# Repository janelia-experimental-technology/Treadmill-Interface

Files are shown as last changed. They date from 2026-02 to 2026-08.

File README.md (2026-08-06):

# Treadmill-Interface
Interface to treadmill encoder with USB-serial and analog outputs

Provides an interface to a treadmill that uses an incremental encoder to monitor speed and distance.
The speed and distance are calculated at each increment of the encoder. Time, speed, and distance are sent out a serial-USB port. The minimum time between readinsg can be set, as well as the time to wait to set zero speed.
The absolute value of speed is also sent out to an SMA connector as an analog signal. Direction is sent out another SMA connector as a 3.3V digital signal. 
The design utilizes a Teensy 4.0.
The encoder voltage provided is 5 volts.

PCB design done in Eagle
Firmware design in Arduino with Teensy extensions
Processor - Teensy 4.0

**Opportunity:** Free to make for Non-Profit Research by downloading the design here. See included hardware license.

Commercial licenses are also available, contact innovation@janelia.hhmi.org and reference this DOI.

For inquiries, please contact [innovation@janelia.hhmi.org](mailto:innovation@janelia.hhmi.org) and reference: Janelia 2017-055

To cite the designs, please cite this DOI: [https://doi.org/10.25378/janelia.33179270](https://doi.org/10.25378/janelia.33179270)

**Related to:** https://doi.org/10.25378/janelia.24691311, item 2017-049

**Other:** supersedes Flintbox ID: 2017-055

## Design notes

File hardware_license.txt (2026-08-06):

Copyright © 2025 Howard Hughes Medical Institute

By downloading, using and/or viewing these designs, documentation and related data and information, and all content in the foregoing (collectively, the “Designs”), you agree to the following:

You may use, copy, modify, display and distribute the Designs for any non-commercial research or educational purpose.

THE DESIGNS ARE PROTOTYPES AND ARE EXPERIMENTAL IN NATURE AND SHOULD BE USED WITH PRUDENCE AND APPROPRIATE CAUTION, AS NOT ALL OF THE CHARACTERISTICS ARE KNOWN. THE DESIGNS ARE PROVIDED “AS-IS” WITHOUT ANY EXPRESS OR IMPLIED WARRANTIES OF ANY KIND (INCLUDING, BUT NOT LIMITED TO, ANY IMPLIED WARRANTIES OF MERCHANTABILITY, NON-INFRINGEMENT, TITLE, ACCURACY, OR FITNESS FOR A PARTICULAR PURPOSE, AND ANY WARRANTIES ARISING FROM COURSE OF PERFORMANCE, COURSE OF DEALING, COURSE OF CONDUCT, OR USAGE OF TRADE) OR CONDITIONS OF ANY KIND, WHETHER EXPRESS OR IMPLIED OR STATUTORY. NO OPINION, ADVICE OR STATEMENT OF THE HOWARD HUGHES MEDICAL INSTITUTE (“HHMI”) OR ITS TRUSTEES, EMPLOYEES, AGENTS, LICENSORS OR SUPPLIERS, WHETHER MADE WITHIN THE DESIGNS OR OTHERWISE, SHALL CREATE ANY WARRANTY. HHMI MAKES NO WARRANTY THAT THE DESIGNS WILL BE ACCURATE, CURRENT OR RELIABLE. SOME JURISDICTIONS DO NOT ALLOW THE EXCLUSION OF CERTAIN WARRANTIES OR CONDITIONS, AND AS A CONSEQUENCE SOME OF THE ABOVE DISCLAIMERS MAY NOT APPLY TO YOU. 

IN NO EVENT SHALL HHMI OR ITS TRUSTEES, EMPLOYEES, AGENTS, LICENSORS OR SUPPLIERS (THE “HHMI PARTIES”) BE LIABLE FOR ANY DIRECT, INDIRECT, INCIDENTAL, SPECIAL, EXEMPLARY, CONSEQUENTIAL, OR PUNITIVE DAMAGES OR LOSSES OF ANY KIND (INCLUDING, BUT NOT LIMITED TO, ANY PROCUREMENT OF SUBSTITUTE GOODS OR SERVICES; LOSS OF USE, BUSINESS, GOODWILL, DATA, REVENUE, OR PROFITS; REASONABLE ROYALTIES; BUSINESS INTERRUPTION; OR OTHER INTANGIBLE LOSSES) HOWEVER CAUSED AND ON ANY THEORY OF LIABILITY, WHETHER IN CONTRACT, STRICT LIABILITY, TORT (INCLUDING, WITHOUT LIMITATION, NEGLIGENCE) OR OTHERWISE, ARISING IN ANY WAY OUT OF THE USE OF, OR INABILITY TO USE, THE DESIGNS, OR FOR ANY OTHER CLAIM RELATED IN ANY WAY TO YOUR USE OF THE DESIGNS OR YOUR INTERACTIONS WITH HHMI, EVEN IF ADVISED OF THE POSSIBILITY OF SUCH DAMAGE OR LOSS, AND NOTWITHSTANDING THE FAILURE OF ESSENTIAL PURPOSE OF ANY LIMITED REMEDY. YOU ACKNOWLEDGE THAT THESE LIMITATIONS ARE REASONABLE, THAT THEY ARE AN ESSENTIAL ELEMENT HEREOF, AND THAT ABSENT SUCH LIMITATIONS, HHMI WOULD NOT MAKE THE DESIGNS AVAILABLE TO YOU OR ENTER INTO THESE TERMS AND CONDITIONS. YOU REMAIN RESPONSIBLE FOR ALL LEGAL COMPLIANCE WITH RESPECT TO YOUR USAGE OF THE DESIGNS. SOME JURISDICTIONS DO NOT ALLOW THE LIMITATION OF LIABILITY FOR INCIDENTAL OR CONSEQUENTIAL DAMAGES, AND AS A CONSEQUENCE SOME OF THE ABOVE LIMITATIONS MAY NOT APPLY TO YOU; IN SUCH JURISDICTIONS, THE LIABILITY OF THE HHMI PARTIES SHALL BE LIMITED TO THE FULLEST EXTENT PERMITTED BY LAW.

Any redistribution of the Designs must contain or reference these terms.

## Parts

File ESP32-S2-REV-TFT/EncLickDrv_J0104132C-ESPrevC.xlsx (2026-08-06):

Partlist exported from Z:/ID&F/TreadmillWithLick/EncoderLickDriver/ECAD/EncLickDrv_J0104132C-ESPrevB.sch at 7/21/2025 11:48 AM
Qty | Value | Device | Designators | Manufacturer | Man PN | Vendor | Vendor PN | $ea | $Total | Notes
1 |  | CON5104361-4 | J7 | TE | 5-104361-4
3 |  | CON21881558 | J3 J4 J6 | Phoenix Contact | 1881558 |  |  | $1.05
1 |  | CON81844743 | J5 | Phoenix Contact | 1848668 |  |  | $7.75
2 |  | DIODE_SCHOTTKYPWRDI-123 | D1 D2 | Diodes Inc | DFLS240-7 | DK | DFLS240-7DIDKR-ND | $0.25
1 |  | POWER_JACK_SHUNTPJ-002 | J1 | CUI | PJ-002BH-SMT-TR |  |  | $1.31
1 | 0 ohm | RESISTOR_SM0805S | R1 | Bournes | CR0805-J/-000ELF | DK | CR0805-J/-000ELFCT-ND | $0.10
3 | 0.1 | CAPS0603S | C2 C4 C5 | Kemet | C0603C104K5RACTU |  |  | $0.11
1 | 0.1 NPO | CAPS1206S | C1 | Kemet | C1206C104J4GACAUTO |  |  | $1.54
1 | 2G17 | 2G17 | U4 | TI | SN74LVC2G17DBVR |  |  | $0.40
2 | 909 | RES SMD 909 OHM 1% 1/8W 0805 | R3 R4 | Stackpole Electronics Inc | RMCF0805FT909R | DK | RMCF0805FT909RCT-ND | $0.10
1 | 53048-05 | 53048-05 | J2 | Molex | 530480560 | DK | 900-0530480560-ND | $0.67
1 | ESP32=S2-REV-TFT-NO16-21 | ESP32=S2-REV-TFT-NO16-21 | M1 | Adafruit | 5345 |  |  | $24.95
2 | RELAY_SSR | RELAY_SSR | U2 U3 | IXYS | CPC1014N |  |  | $1.25
1 | TLV9301 | AD8065RT | U1 | Analog Devices | AD8603AUJZ-REEL |  |  | $2.62
2 | 10K0 ohm | RES SMD 10K OHM 1% 1/8W 0805 | R2 R5 | Bourns | CR0805-FX-1002ELF | DK | CR0805-FX-1002ELFCT-ND | $0.10
 |  | Mate for 1991558 |  | Phoenix | 1881325 |  |  | $2.80
1 | 5 pin header RA | CONN HEADER R/A 5POS 2.54MM | J2 | TE | 5-104361-4 | DK | A33964-ND | $1.74 | Alternate
 |  |  |  |  |  |  | TOTAL | $46.74
 |  | BOARD design can be found at:
 |  | https://oshpark.com/shared_projects/oZUU0shd

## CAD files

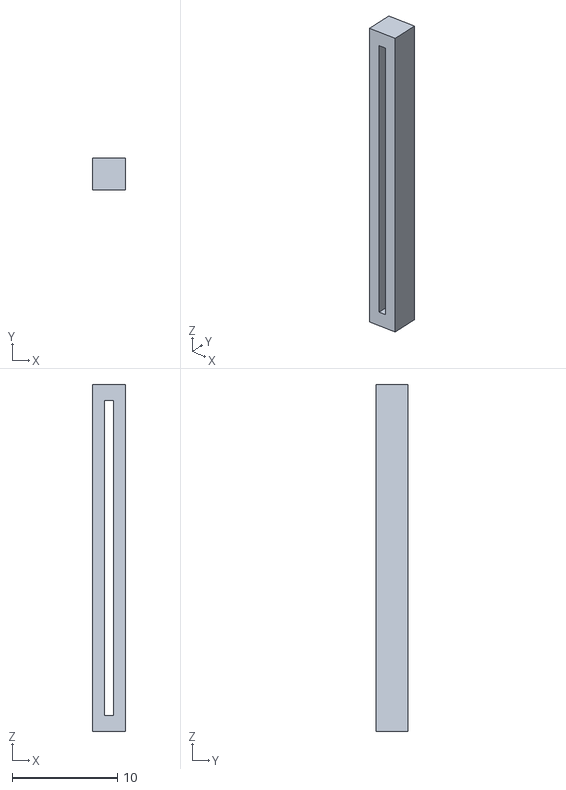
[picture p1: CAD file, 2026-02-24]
MCAD/riser12pin.stl
3.17 x 3.05 x 33.0

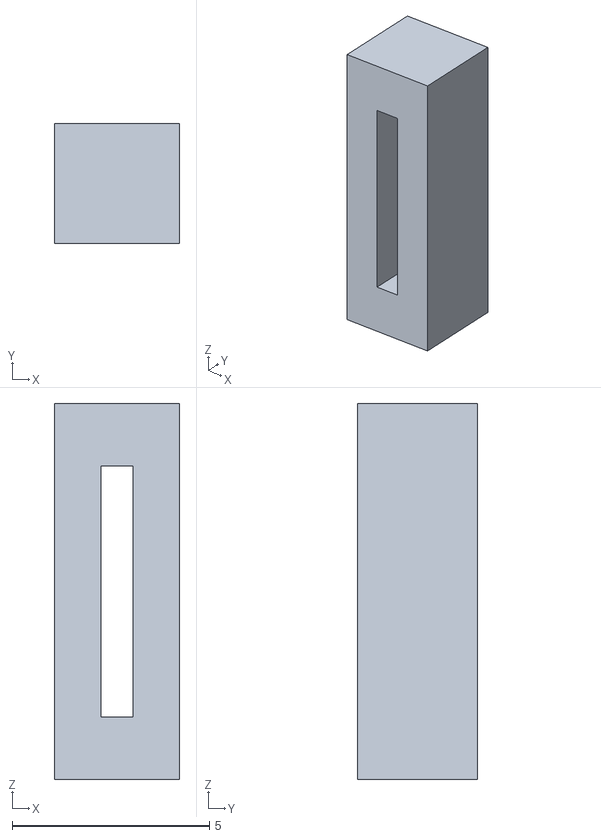
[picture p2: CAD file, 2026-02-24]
MCAD/riser3pin.stl
3.17 x 3.05 x 9.52

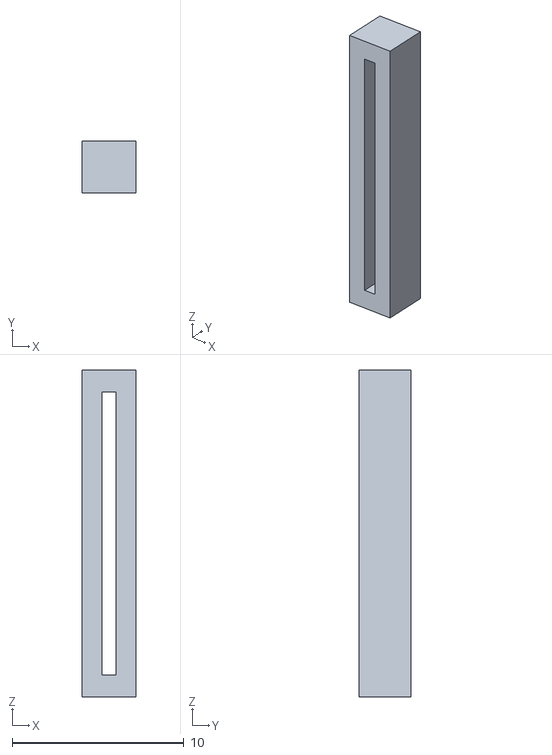
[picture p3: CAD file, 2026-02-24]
MCAD/riser7pin.stl
3.17 x 3.05 x 19.0

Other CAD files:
MCAD/BLK-esp32-rev-tft-back-largeEncoderConn.ipt
MCAD/BLK-esp32-rev-tft-bezel.ipt
MCAD/OldVersions/riser12pin.0003.ipt
MCAD/OldVersions/riser3pin.0002.ipt
MCAD/OldVersions/riser7pin.0001.ipt
MCAD/riser12pin.ipt
MCAD/riser3pin.ipt
MCAD/riser7pin.ipt

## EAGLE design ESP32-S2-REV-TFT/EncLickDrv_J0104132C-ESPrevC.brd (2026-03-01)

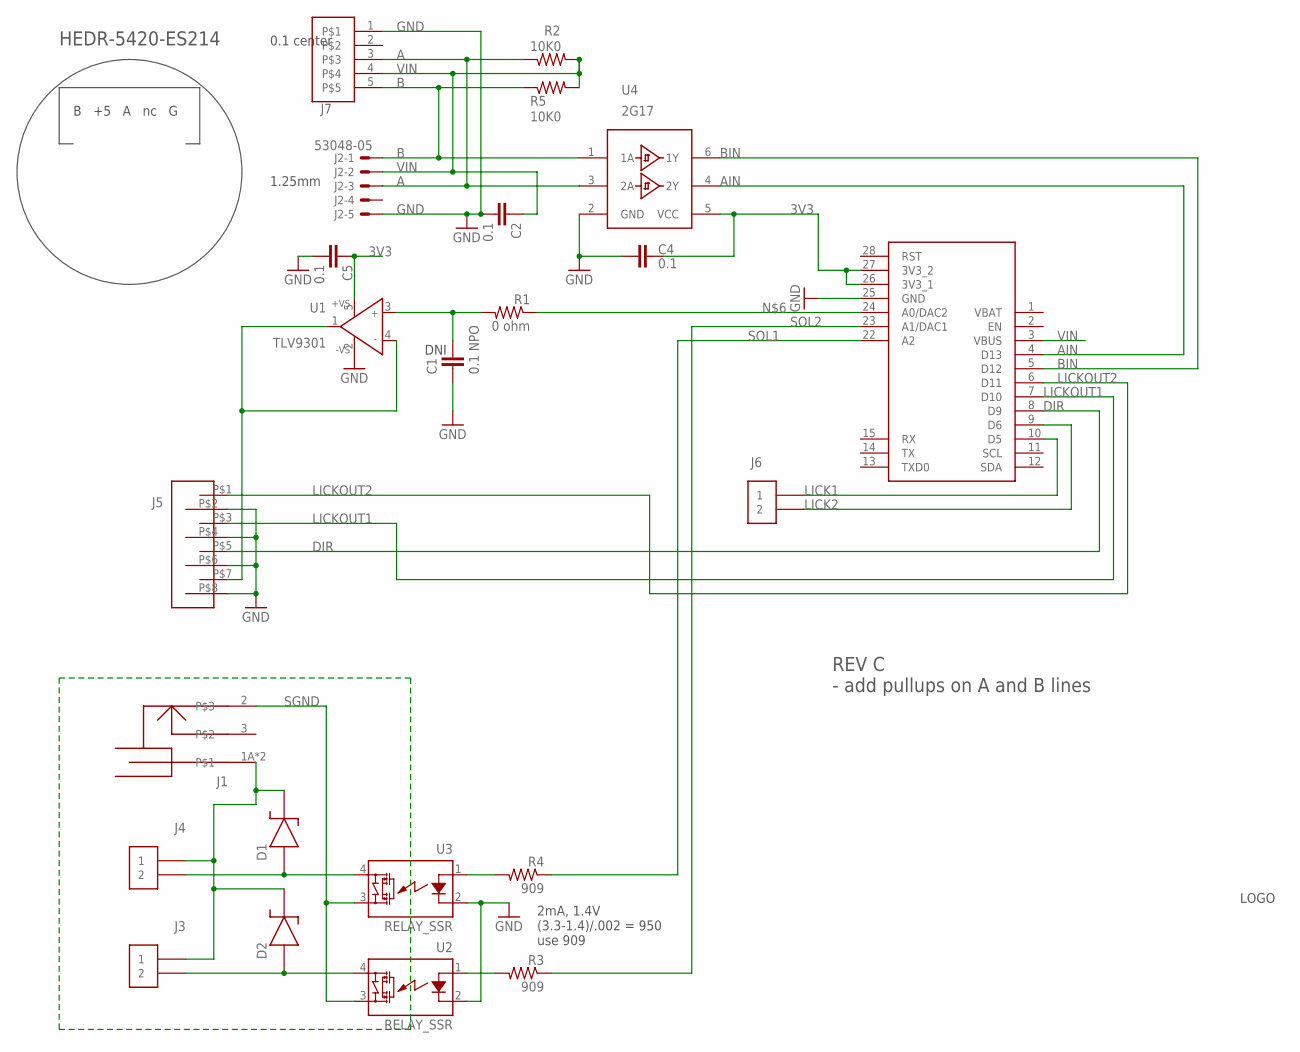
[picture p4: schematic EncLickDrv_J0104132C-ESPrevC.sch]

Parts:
C1: 0.1 NPO; 1206S
C2, C4, C5: 0.1; 0603S
D1, D2: DIODE_SCHOTTKYPWRDI-123; PWRDI-123
J1: POWER_JACK_SHUNTPJ-002; PJ-002
J2: 53048-05
J3, J4, J6: CON21881558; 1881558
J5: CON81844743; 1844743
J7: CON5104361-4; 104361-4
M1: ESP32=S2-REV-TFT-NO16-21; ESP32-S2-REV-TFT-NO16-21
R1: 0 ohm; 0805S
R2, R5: 10K0; 0805S
R3, R4: 909; 0805S
U1: TLV9301; SOT23-5
U2, U3: RELAY_SSR; SSR_SOIP
U4: 2G17; SOT23-6
U$1: JFRC-LOGOLOGO_OP; LOGO_BMP_OP

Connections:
3V3: C4.1, C5.1, M1.26 (3V3_1), M1.27 (3V3_2), U1.5 (+VS), U4.5 (VCC)
A: J2.3, J7.3, R2.1, U4.3 (2A)
AIN: M1.4 (D13), U4.4 (2Y)
B: J2.1, J7.5, R5.1, U4.1 (1A)
BIN: M1.5 (D12), U4.6 (1Y)
DIR: J5.P$5 (5), M1.8 (D9)
GND: C1.2, C2.2, C4.2, C5.2, J2.5, J5.P$2 (2), J5.P$4 (4), J5.P$6 (6), J5.P$8 (8), J7.1, M1.25 (GND), U1.2 (-VS), U2.2 (K), U3.2 (K), U4.2 (GND)
LICK1: J6.1, M1.10 (D5)
LICK2: J6.2, M1.9 (D6)
LICKOUT1: J5.P$3 (3), M1.7 (D10)
LICKOUT2: J5.P$1 (1), M1.6 (D11)
unnamed: D1.A, J4.2, U3.4 (DS1)
unnamed: D2.A, J3.2, U2.4 (DS1)
unnamed: D1.K, D2.K, J1.1A, J1.1B, J3.1, J4.1
unnamed: M1.24 (A0/DAC2), R1.1
unnamed: R4.2, U3.1 (A)
unnamed: R3.2, U2.1 (A)
unnamed: J5.P$7 (7), U1.1 (OUT), U1.4 (IN-)
unnamed: C1.1, R1.2, U1.3 (IN+)
SGND: J1.2, U2.3 (DS2), U3.3 (DS2)
SOL1: M1.22 (A2), R4.1
SOL2: M1.23 (A1/DAC1), R3.1
VIN: C2.1, J2.2, J7.4, M1.3 (VBUS), R2.2, R5.2

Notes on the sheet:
B +5 A nc G
HEDR-5420-ES214
1.25mm
2mA, 1.4V (3.3-1.4)/.002 = 950 use 909
DNI
0.1 center
REV C - add pullups on A and B lines

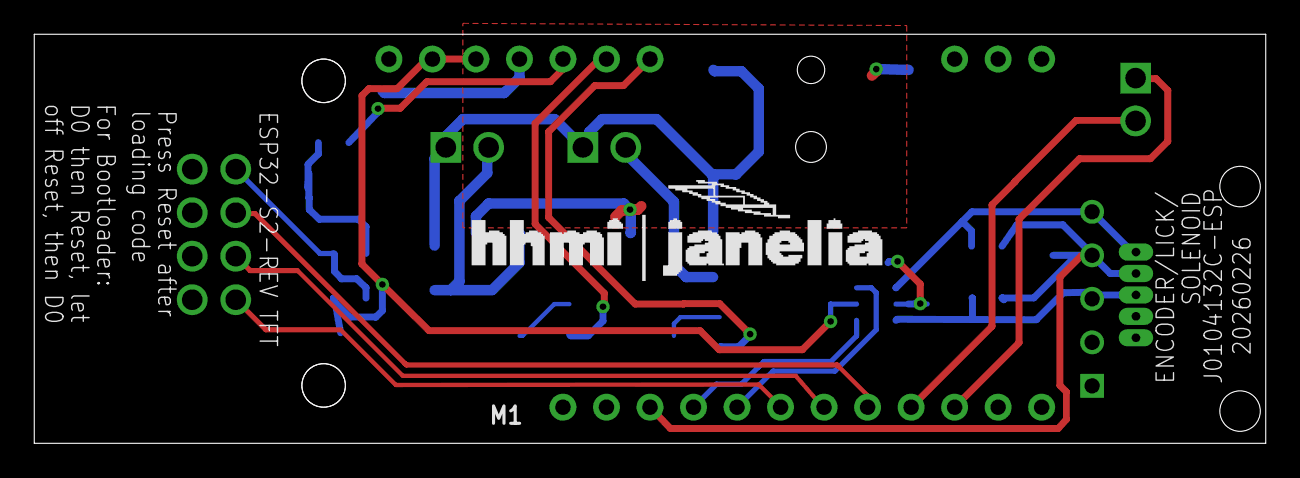
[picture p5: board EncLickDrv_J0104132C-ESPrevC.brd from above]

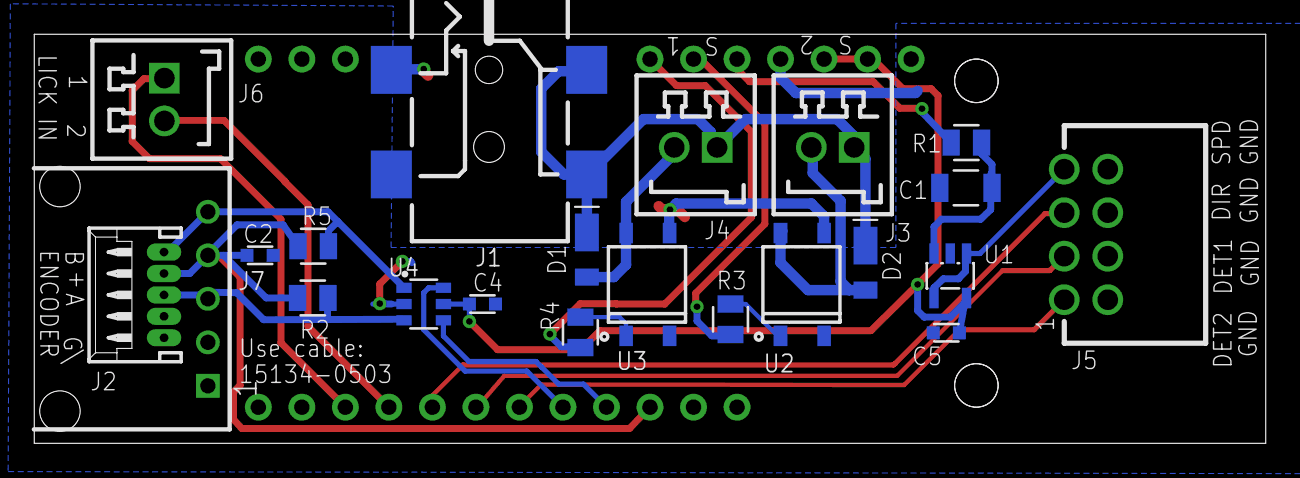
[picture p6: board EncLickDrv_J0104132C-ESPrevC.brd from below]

Board: 2 copper layers, 71.9 x 23.9 mm, 24 parts (23 on the bottom side), 23 nets.

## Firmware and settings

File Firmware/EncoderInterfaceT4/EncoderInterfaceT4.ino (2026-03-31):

 // EncoderInterfaceT4
//
//  Read the encoder and translate to a distance and send over USB-Serial and PWM DAC
//  Teensy 4.0 with Teensy Extensions

//  Encoder A - pin 14
//  Encoder B - pin 15
//  Encoder VCC - Vin
//  Encoder ground - GND
//  PWM Analog Out - pin 3
//  Direction pin - pin 21
//
// Steve Sawtelle
// jET
// Janelia
// HHMI 
//

#define SHOW_MICROS    // if defined, print micros() with each output
#define SHOW_REVERSE   // if this is defined, show abs value of speed, else ignore reverse distance/speed
#define SHOW_ZERO      // if this is defined, show 0 speed if no movement in SPEED_TIMEOUT micros
//#define CYLINDER_8IN   // if this is defined, will compile for 8" cyclinder, else standard belt 

#define ZERO_OFFSET    // if this is defined, offset zero to 1/2 Max DAC to allow sending reverse speed through DAC
//                          if used must also define SHOW_REVERSE

#define UPDATE_USECS 20000  // don't print faster than this many micros
#define SPEED_TIMEOUT 100000  // if we don't move in this many micros assume we are stopped and show 0.0 speed 


#define VERSION "20260331"
// ===== VERSIONS ======

// 20260331 sws
// - implemement zero offset 

// 20240909 sws
// - from EncoderInterfaceT3, changes to use Teensy 4.0
//   pin changes
//   add in spped and dir outputs, speed is PWM analog

// 20230621 sws
// - add ability to compile for cylinder treadmill

// 20230523 sws
// - remove debug output in loop
// - add '?' query for version

// 20220419 sws
// - update lastUsecs during zero speed time so that when the treadmill starts again the speed 
//   is based on the end of last zero time out

// 20221212 sws from suggestions by york at Labmaker
// - strict even intervals causes poor low speed granularity
// - so, return to incremental updates, but limit to no faster than UPDATE_USECS 
// - make define to allow showing zero if no movement in SPEED_TIMEOUT micros
// - add define to allow printing of micros() value

// 20221017 sws
// - add define to print distance and speed at even intervals. 
//     To use allow #define TIMED_UPDATE and UPDATE_RATE sets the rate in updates per second

// 20220720 sws
// - also need to use pin 3 not 0 in LC as 0 doesn't have interrupt capability
// - to keep backward compatibility, set the unused pin as input so they can be tied
//    together on PCB

// 20220711 sws
// - provide alternate compile for Teensy LC, A12 not A14 for DAC

// 20211109 sws
// - was printing absolute run speed, now it shows as negative if reverse

// 20211021 sws
// - add define for offsetting DAC to show reverse speed 

// 20180514 sws
// - DIR pin was set to 12 but hardware has it on 2
// - also had index pin as 2 should be 14

// 20180328 sws
// - remove wait for serial since it will not move past it if no serial port is defined

// 20180319 sws
// - add define to allow showing reverse direction

#define MAXSPEED    1000.0f  // maximum speed for dac out (mm/sec)
#define MAXDACVOLTS 2.5f    // DAC ouput voltage at maximum speed
#define MAXDACCNTS  4095.0f // maximum dac value - should be 2^(analogWriteResolution)

float maxDACval = MAXDACVOLTS * MAXDACCNTS / 3.3; // limit dac output to max allowed

#define speedPin 3    
#define encAPin 14 // 12
#define encBPin 15 // 11
#define dirPin 21    // 0 = forward,1 = reverse


#ifdef CYLINDER_8IN
// counts per rotation of cylindrical treadmill encoder wheel: 200 counts per rev, 7.90" per rev (was 7.95)
// so - 7.90 * 25.4 * pi / 200  = microns/cnt
// when using rising and falling edges of both channels, must divide by 800
// first version of cylinder used /200 and then /4 in distance per count, but the /4 should be here
#define MM_PER_COUNT 787990  // 3171909  // actually 1/10^6mm per count since we divide by usecs
#else
// counts per rotation of treadmill encoder wheel
// 200 counts per rev
// 1.03" per rev
// so - 1.03 * 25.4 * pi / 200 /1000 = microns/cnt
#define MM_PER_COUNT 410950  // actually 1/10^6mm per count since we divide by usecs
#endif

#define DIST_PER_COUNT ((float)MM_PER_COUNT/1000000.0)   //(float)0.41095
 
#define SPEED_TIMEOUT 100000  // if we don't move in this many microseconds assume we are stopped

static float runSpeed = 0;
static float lastSpeed = 0;
volatile uint32_t lastUsecs;
volatile uint32_t thisUsecs;
volatile uint32_t encoderUsecs;
volatile float distance = 0;
volatile float deltaDistance = 0;
volatile int8_t encoderCounts = 0;

#define FW 1
#define BW -1

int dir = FW;

float lastDistance;
float zeroDistance;
volatile boolean movement = false;

// ------------------------------------------
// interrupt routine for ENCODER_A rising edge (and falling if cylinder)
// ---------------------------------------------
void encoderInt()
{   
   thisUsecs = micros();
  
  int ENCA = digitalReadFast(encAPin);  // always update output 
  int ENCB = digitalReadFast(encBPin); 
  // figure out the direction  
    
  if (ENCA == ENCB )  // if same, then backwards
  {   
    dir = BW;
    #ifdef SHOW_REVERSE 
        distance -= DIST_PER_COUNT;
    #endif
  }  
  else
  {
      dir = FW;
      distance += DIST_PER_COUNT;
  }  
   
  #ifndef SHOW_REVERSE   // if not showing reverse speed force reverse to 0
    if( dir == BW ) runSpeed = 0;      
  #endif  

   movement = true;  
     
}


// ------------------------------------------
// interrupt routine for ENCODER_B rising/falling edge - for 8" cylinder
// ---------------------------------------------
void encoderBInt()
{   
   thisUsecs = micros();
  
  int ENCA = digitalReadFast(encAPin);  // always update output 
  int ENCB = digitalReadFast(encBPin); 
  // figure out the direction  
    
  if (ENCA != ENCB )  // if same, then backwards
  {   
    dir = BW;
    #ifdef SHOW_REVERSE 
        distance -= DIST_PER_COUNT;
    #endif
  }  
  else
  {
      dir = FW;
      distance += DIST_PER_COUNT;
  }  
   
  #ifndef SHOW_REVERSE   // if not showing reverse speed force reverse to 0
    if( dir == BW ) runSpeed = 0;      
  #endif  

   movement = true;  
     
}

void setDACspeed(float speed)
{

  #ifdef ZERO_OFFSET  
    float dacval = ((speed/MAXSPEED * maxDACval) + maxDACval)/2; 
  #else  
    float dacval = abs(speed)/MAXSPEED * maxDACval; 
  #endif

    if( dacval < 0 ) dacval = 0;             
    if( dacval > maxDACval) dacval = maxDACval; 

    analogWrite(speedPin,(uint16_t) dacval);
       
    if( runSpeed < 0 ) 
       digitalWrite(dirPin, HIGH); // and note reverse dir 
    else
       digitalWrite(dirPin, LOW);  // else note forward
}
       

void setup()
{

  Serial.begin(192000);
  // while( !Serial);  // if no USB serial connection, this will hang the program
  
  pinMode(encAPin, INPUT_PULLUP); // sets the digital pin as input
  pinMode(encBPin, INPUT_PULLUP); // sets the digital pin as input
  pinMode(dirPin, OUTPUT);
  digitalWrite(dirPin, LOW);  //  assume forward
  
  analogWriteFrequency(speedPin, 36621.09);  // optimal freq for 12 bit PWM
  // https://www.pjrc.com/teensy/td_pulse.html
  analogWriteResolution(12);

  lastUsecs = micros();
  thisUsecs = lastUsecs;
  lastDistance = 0;
  zeroDistance = 0;
  #ifdef CYLINDER_8IN
    attachInterrupt(encAPin, encoderInt, CHANGE); // check encoder every A pin edge
    attachInterrupt(encBPin, encoderBInt, CHANGE); // check encoder every B pin edge
  #else
    attachInterrupt(encAPin, encoderInt, RISING); // check encoder every A pin rising edge
  #endif  

  setDACspeed(0);

}

boolean moved = false;

 void loop() 
{  

  if( Serial.available() )
  {
     int8_t charin = Serial.read();
     while(Serial.available()); // clear buffer
     if ( charin == '?' )
     {
       Serial.print("Treadmill V:");
       Serial.println(VERSION);
       #ifdef CYLINDER_8IN
          Serial.println("8in Cylindrical Treadmill");
       #endif   
       #ifdef SHOW_MICROS 
          Serial.print("micros,");
       #endif
       Serial.println("distance (mm),speed (mm/s)");     
     } 
     else if ( charin == 'c' )
     {
       float speed;
      #ifdef ZERO_OFFSET
        Serial.print("Speed output calibrate, ");
        Serial.print(-MAXSPEED);
        Serial.print(" to ");
        Serial.print(-MAXSPEED);
        Serial.println(" mm/sec");
        for( speed =-MAXSPEED; speed <= MAXSPEED; speed += MAXSPEED/5)
      #else  
        Serial.print("Speed output calibrate, 0 to ");
        Serial.print(MAXSPEED);
        Serial.println(" mm/sec");
        for( speed = 0; speed <= MAXSPEED; speed += MAXSPEED/5)
      #endif
        {
           setDACspeed(speed);
           Serial.println(speed);
           delay(5000);
        }  
        setDACspeed(0);   
     }
  }
  
  noInterrupts();
  uint32_t newUsecs = thisUsecs;
  float cumDistance = distance;
  moved = movement;
  movement = false;
  interrupts();
  
  if( (moved) && ((newUsecs - lastUsecs) > UPDATE_USECS ) ) // are we at least past max update rate
  {
  #ifndef SHOW_REVERSE 
     if( (cumDistance - lastDistance) > 0 )
  #endif     
     { 
       int32_t usecs = newUsecs - lastUsecs;        
       lastUsecs = newUsecs;  
       runSpeed = (1e6 * (cumDistance - lastDistance) ) / (float)usecs;
       #ifdef SHOW_MICROS     
         Serial.print(newUsecs);   
         Serial.print(","); 
         
       #endif     
       Serial.print(cumDistance);
       Serial.print(",");
       Serial.println( runSpeed); 
            
       lastDistance = cumDistance;

       setDACspeed(runSpeed);
     }
     
  }
  #ifdef SHOW_ZERO
  else 
  {
     uint32_t zeroUsecs = micros();
     if( (zeroUsecs - lastUsecs) > SPEED_TIMEOUT )
     {
       if( lastDistance != zeroDistance )
       {
         #ifdef SHOW_MICROS        
           Serial.print(zeroUsecs);  
           Serial.print(",");           
         #endif         
         Serial.print(lastDistance);
         Serial.println(",0.0");  
           
         zeroDistance = lastDistance;
       }  
       
       lastUsecs = zeroUsecs;  // update to most recent time so next speed reading is right
     }   
  } 
  #endif 


} // end loop

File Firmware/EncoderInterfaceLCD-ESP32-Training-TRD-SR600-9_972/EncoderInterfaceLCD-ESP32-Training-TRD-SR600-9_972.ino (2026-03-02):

 // Treadmill-LCD
//
//  Read the encoder and translate to speed and distance
//  Send over USB-Serial and show on display 
//  Start and Stop buttons to zero distance and stop recording distance and speed
//  Uses Adafruit ESP32-S2 Reverse TFT Feather
//
//  Start Button - pin 1
//  Stop Button - pin 2
//  Encoder A  - pin 13
//  Encoder B - pin 14
//  Encoder VCC - Vin
//  Encoder ground - GND
//
// Steve Sawtelle
// jET
// Janelia
// HHMI 
//

#include <Cmd.h>
#include <EEPROM.h>

#define EEPROM_SIZE 64 

//#define SHOW_MICROS    // if defined, print micros() with each output
#define SHOW_REVERSE   // if this is defined, show abs value of speed, else ignore reverse distance/speed
#define SHOW_ZERO      // if this is defined, show 0 speed if no movement in SPEED_TIMEOUT micros
#define CYLINDER_6IN   // if this is defined, will compile for 6.06" cylinder, else standard belt 
#define REVERSE_DIR    // if defined will swap direction sense

//#define ZERO_OFFSET    // if this is defined, offset zero to 1/2 Max DAC to allow sending reverse speed through DAC
//                          if used must also define SHOW_REVERSE

#define UPDATE_USECS 100000  // don't print faster than this many micros
#define SPEED_TIMEOUT 200000  // if we don't move in this many micros assume we are stopped and show 0.0 speed 

#define MINON 1
#define MAXON 100


#define VERSION "20260302"

// ===== VERSIONS ======

// 20260302 scj
// changed UPDATE_USECS and SPEED_TIMOUT for a 10Hz refresh rate
// removed redundant definition of SPEED_TIMOUT

// 20260225 sws
// add ID command

// 2026011 sws
// - 9.972" diameter rat wheel 600 count encoder

// 20250729 sws
// - if speed is zero, was showing speed calculated from last distance just once
//    now, if zero, keep updating the average 

// 20250402 sws
//  - version for TRD-SR1000 with 170mm diameter wheel

// 20240410 sws
// - using 2048 cpr encoder, so only use 1 edge of A 

// 20240409 sws
// - from PACHITARIU code, change cylinder size
// -using 'D' rev board - Ain is 13 not A0, Bin is 12 not A1

// 20231107 sws
// - add pull ups and downs on button pins

// 20231106 sws
// - reverse forward and backward
// - show speed as average since the start of the run (distance over elapsed time) 
// - show version number after reset for 2 secs

// 20231018 sws
// - from T3 Encoder Interface 
// - LCD display, work on ESP32-S3 Reverse TFT Feather

// 20230621 sws
// - add ability to compile for cylinder treadmill

// 20230523 sws
// - remove debug output in loop
// - add '?' query for version

// 20220419 sws
// - update lastUsecs during zero speed time so that when the treadmill starts again the speed 
//   is based on the end of last zero time out

// 20221212 sws from suggestions by york at Labmaker
// - strict even intervals causes poor low speed granularity
// - so, return to incremental updates, but limit to no faster than UPDATE_USECS 
// - make define to allow showing zero if no movement in SPEED_TIMEOUT micros
// - add define to allow printing of micros() value

// 20221017 sws
// - add define to print distance and speed at even intervals. 
//     To use allow #define TIMED_UPDATE and UPDATE_RATE sets the rate in updates per second

// 20220720 sws
// - also need to use pin 3 not 0 in LC as 0 doesn't have interrupt capability
// - to keep backward compatibility, set the unused pin as input so they can be tied
//    together on PCB

// 20220711 sws
// - provide alternate compile for Teensy LC, A12 not A14 for DAC

// 20211109 sws
// - was printing absolute run speed, now it shows as negative if reverse

// 20211021 sws
// - add define for offsetting DAC to show reverse speed 

// 20180514 sws
// - DIR pin was set to 12 but hardware has it on 2
// - also had index pin as 2 should be 14

// 20180328 sws
// - remove wait for serial since it will not move past it if no serial port is defined

// 20180319 sws
// - add define to allow showing reverse direction

#include <Adafruit_GFX.h>    // Core graphics library
#include <Adafruit_ST7789.h> // Hardware-specific library for ST7789
#include <SPI.h>
#include <elapsedMillis.h>

Adafruit_ST7789 tft = Adafruit_ST7789(TFT_CS, TFT_DC, TFT_RST);

#define MAXSPEED    1000.0f  // maximum speed for dac out (mm/sec)
#define MAXDACVOLTS 2.5f    // DAC ouput voltage at maximum speed
#define MAXDACCNTS  4095.0f // maximum dac value


#define encAPin 13
#define encBPin 12 
#define startButton 1
#define stopButton 2
#define sol1Pin 16

#define MM_PER_COUNT 1326217   // TDR600, 9.972" dia wheel, 600 count encoder
//#define MM_PER_COUNT 534000  // for TDR-SR1000 1000 counts, 170mm diameter// 787990  // 3171909  // actually 1/10^6mm per count since we divide by usecs

#define DIST_PER_COUNT ((float)MM_PER_COUNT/1000000.0)   //(float)0.41095

static float runSpeed = 0;
static float lastSpeed = 0;
volatile uint32_t lastUsecs;
volatile uint32_t thisUsecs;
volatile uint32_t encoderUsecs;
volatile float distance = 0;
volatile float deltaDistance = 0;
volatile int8_t encoderCounts = 0;

#define MAXIDX 200
volatile float distVals[MAXIDX];
volatile uint32_t microVals[MAXIDX];
volatile uint8_t idx = 0;

#define ST77XX_GRAY 0x8410

#define FW 1
#define BW -1

int dir = FW;

float lastDistance;
float zeroDistance;
volatile boolean movement = false;
uint32_t startMillis;

// ------------------------------------------
// interrupt routine for ENCODER_A rising edge (and falling if cylinder)
// ---------------------------------------------
void encoderInt()
{   
   thisUsecs = micros();
  
  int ENCA = digitalRead(encAPin);  // always update output 
  int ENCB = digitalRead(encBPin); 
  // figure out the direction  

#ifdef REVERSE_DIR    
  if (ENCA != ENCB )  // if not same, then backwards
#else
  if (ENCA == ENCB )  // if same, then backwards
#endif 

  
  {   
//    Serial.print('B');
    dir = BW;
    #ifdef SHOW_REVERSE 
        distance -= DIST_PER_COUNT;
    #endif
  }  
  else
  {
//    Serial.print('F');
      dir = FW;
      distance += DIST_PER_COUNT;
  }  
   
  #ifndef SHOW_REVERSE   // if not showing reverse speed force reverse to 0
    if( dir == BW ) runSpeed = 0;      
  #endif  

   movement = true;

//   if( idx < MAXIDX)
//   {
//      distVals[idx] = distance;
//      microVals[idx] = thisUsecs;
//      idx++;
//   }   
     
}


// ------------------------------------------
// interrupt routine for ENCODER_B rising/falling edge
// ---------------------------------------------
void encoderBInt()
{   
   thisUsecs = micros();
  
  int ENCA = digitalRead(encAPin);  // always update output 
  int ENCB = digitalRead(encBPin); 
  // figure out the direction
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

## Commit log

2026-01-07 ESO board and housing
    [BLK-esp32-rev-tft-back-largeEncoderConn.ipt, BLK-esp32-rev-tft-bezel.ipt, EncLickDrv_J0104132C-ESPrevB.brd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]
2026-02-24 ADD FW
    [riser12pin.0003.ipt, riser12pin.ipt, riser12pin.stl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]
2026-03-01 add pullups
    [EncLickDrv_J0104132C-ESPrevC.brd, EncLickDrv_J0104132C-ESPrevC.sch]
2026-03-02 Added software files for data acquisition from multiple treadmills at the same time Updated the encoder board firmware to operate at 10Hz instead of 50Hz
2026-03-31 make zero offset functional in EncoderInterfaceT4
2026-07-27 Add 10K resistors, add manufacturer info
    [EncLickDrv_J0104132C-ESPrevC.xlsx]
2026-07-27 add board design link
    [EncLickDrv_J0104132C-ESPrevC.xlsx]
2026-08-06 Update readme, add license file
    [EncLickDrv_J0104132C-ESPrevC.xlsx]

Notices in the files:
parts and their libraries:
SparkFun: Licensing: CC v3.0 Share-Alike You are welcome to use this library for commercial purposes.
